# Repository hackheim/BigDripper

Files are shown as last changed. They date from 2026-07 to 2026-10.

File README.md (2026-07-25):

# Big Dripper 

### BigDripper – Controller Board and Operating Principle

BigDripper is Hackheim’s version of the classic bicycle-mounted water printer (see links below). The printer is being developed as a community project, with the goal of having it completed by the end of September 2026.

The printer consists of 16 solenoid valves mounted in a row across the bicycle trailer. The valves are supplied with water from a tank and pump. When a valve is opened briefly, it releases a small amount of water onto the ground, forming a single pixel. Together, the 16 valves produce one vertical column of 16 pixels. As the bicycle moves forward and new columns are printed in sequence, the trailer effectively operates as a large-scale dot-matrix printer.

An encoder measures the distance travelled by the bicycle. Rather than advancing through the image at fixed time intervals, the controller selects the next column after the bicycle has travelled a predefined distance. This helps maintain the proportions of the printed text or graphics even when the cycling speed varies.

### Controller board

The controller is based on an ESP32-S3 DevKitC-1, which plugs into a custom-designed carrier board. To make the board easy to maintain and repair—and also suitable for educational use and soldering workshops—we have chosen to use through-hole components throughout the carrier board.

The board has a nominal input voltage of 12 V, which is also the operating voltage of the solenoid valves. A TL2575-based switching regulator generates 5 V for the ESP32 development board and the other logic circuitry.

The regulator itself supports an input voltage of up to 40 V. However, the input voltage is also supplied directly to the solenoid valves. When using a voltage higher than 12 V, both the valves and all other components connected to the input-voltage rail must therefore be rated for the selected voltage.

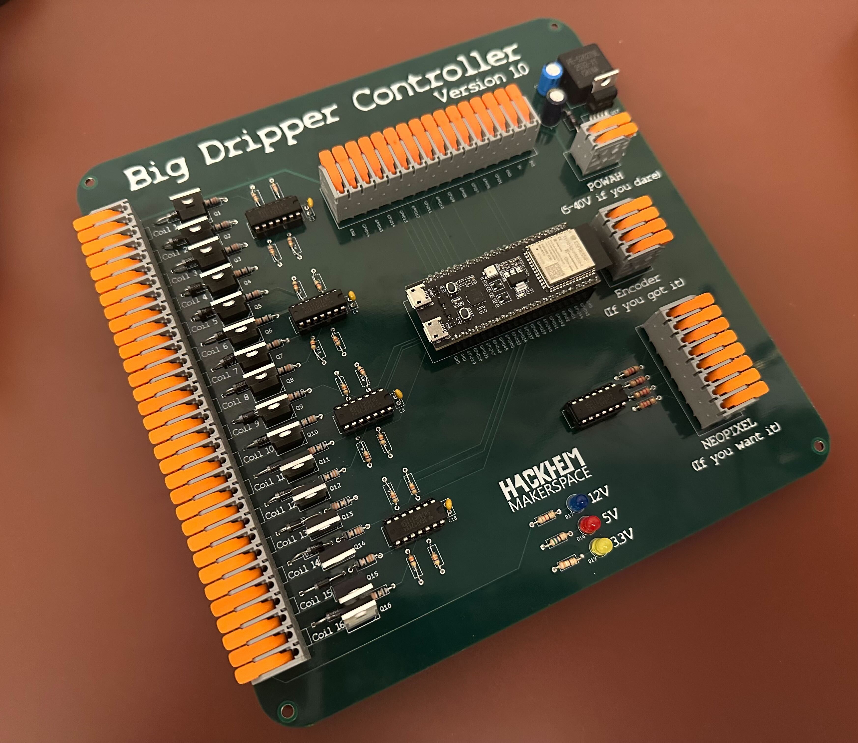
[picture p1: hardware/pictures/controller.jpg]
controller


### Solenoid valve control

The 16 valve outputs are controlled by IRL540N MOSFETs in a low-side switching configuration. The control signals from the ESP32 use 3.3 V logic and are therefore routed through SN74HCT125NE4 buffers powered from 5 V. These buffers provide logic-level translation and drive the MOSFET gates at a higher and more suitable voltage.

Each MOSFET gate is connected to its buffer output through a 33-ohm series resistor. The control signals also have 47-kilohm pull-down resistors, ensuring that the valves remain switched off while the ESP32 is starting, being reset, or not actively driving the outputs.

Each valve output is protected by a dedicated 1N4007 flyback diode. The diode suppresses the inductive voltage spike generated when the current through the solenoid coil is interrupted, protecting the MOSFET from excessive drain voltage.

### Connections and expansion options

The board has a dedicated input for an encoder with transistor outputs and A/B signals. An additional header provides access to 12 spare GPIO signals, together with 3.3 V, 5 V, and ground connections.

Four separate outputs are available for NeoPixel LEDs. These signals are also level-shifted from 3.3 V to 5 V using an SN74HCT125 buffer, and each data output includes a 330-ohm series resistor.

The board also includes indicator LEDs for the 12 V, 5 V, and 3.3 V supply rails, making it easy to verify that the different supply voltages are present.

All external inputs and outputs use WAGO board-to-wire lever connectors, allowing wires to be connected and removed easily without tools.

### Schematic

[schematic](./hardware/pdf/schematic.pdf)

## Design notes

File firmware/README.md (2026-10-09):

# Firmware demo

This code contains logic for controlling 16 valves and also reading input from a quadrature encoder. Valve control and quadrature logic is running on separate cores

## Building and flashing

1. Disconnect USB port
1. Press BOOT button
1. Reconnect USB port
1. pio run -t upload -t monitor
1. Press "Reset" on the ESP32

## Text input

1. Connect to the BigDripper SSID and enter the password "dripdrip1"
1. Go to http://bigdripper.local (fallback http://192.168.4.1) to queue text to print
1. Go to http://bigdripper.local/params for scaling/length/pause settings (user "admin", password "letmeprint9")
1. Each message prints in the font picked above the text box: Spleen (the original Spleen 8x16 font), Drip or Drip bold. Drip and Drip bold have A-Z, ÆØÅ, 0-9 and `. , ! ? - : '`; Spleen only has A-Z, 0-9 and space. Anything a font doesn't have prints as a space. The Invert button next to the fonts prints the message inverted: dry letters in a sprayed band, with 2 solid columns on each side. This uses a lot more water than normal text. Emoji are written as shortcodes (the web page has a button for each): `:smile:` `:sad:` `:big_smile:` `:neutral:` `:confused:` `:wink:` `:surprised:` `:tongue:` `:heart:` `:drop:` `:star:`. The length limit counts printed characters, so an emoji counts as one.

## Font

The Drip glyphs are defined in `font_design/gen_font.py`, and the Spleen font's bitmaps in `font_design/spleen_8x16.py`. After changing it, regenerate the preview and the firmware tables from this directory:

    python3 font_design/gen_font.py font_design/font_preview.txt
    python3 font_design/gen_font.py --c src/font_data.cpp

`font_design/host_test/` builds `font.cpp` on the host (needs `g++`) and checks the fonts, the emoji shortcodes and the length counting:

    sh font_design/host_test/run.sh

## Console preview

Check what the head prints at the bench, without water. Two extra build environments draw every column that fires on the serial console as one line of text; turn the wheel and the message scrolls by column by column.

    pio run -e preview -t upload -t monitor        # preview, valves fire as normal
    pio run -e preview-dry -t upload -t monitor    # preview, valves never open (dry run)

Add `--upload-port` / `--monitor-port` if the CP2102 isn't at the port in `platformio.ini`. On Linux it's usually `/dev/ttyUSB*` (e.g. `--upload-port /dev/ttyUSB1`), or watch it with `pio device monitor -p /dev/ttyUSB1 -b 115200`. If `pio` isn't on your PATH, it's `~/.platformio/penv/bin/pio`. A plain `pio run` still builds only the normal firmware. **Flash the normal firmware (`pio run -t upload`) again before riding**: a dry-run board prints `*** DRY RUN: valves disabled ***` at boot and its web page shows a red "DRY RUN — valves disabled" line.

The preview is on the CP2102 port ("UART", the one used for flashing; `Serial0` in the code), not the native USB port. If nothing shows up, check which port you're watching first.

How to read it: each line is one column, 16 characters, `#` = valve open, `.` = closed, COIL1 on the left. Columns appear top to bottom in the order they fire. **Rotate the screen 90° anticlockwise** (left edge down) and the text reads the right way up, first column on the left. It shows the coil bits actually written, so if the preview reads mirrored, the ground print is mirrored too. `HI` in Drip looks like this:

    -- HI [Drip] --
    ################
    .......##.......
    .......##.......
    .......##.......
    .......##.......
    .......##.......
    .......##.......
    .......##.......
    ################
    ................
    ................
    ................
    ##............##
    ##............##
    ################
    ##............##
    ##............##

Other lines: `-- mode: lines --` when the mode changes (Prime and Trace draw nothing, Lines draws its columns), `~~ skipped 3 ~~` when the wheel jumped past columns between two scans (those never fire on the ground either), and `!! dropped 12 lines` if the console fell behind a fast spin. Dropped lines only affect the preview, never the valves.

Under the hood these are the build flags `-D CONSOLE_PREVIEW=1` and `-D CONSOLE_PREVIEW_DRY_RUN=1`, which also work on their own.

## Debugging

1. Make sure that the CP210x driver is installed oin the machine you are debugging on. If not, the UART port will not enumerate

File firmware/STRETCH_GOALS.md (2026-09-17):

# Stretch goal

* Use for extra switches on control panel ?
    * Font change ?
    * Bold / Italics ?

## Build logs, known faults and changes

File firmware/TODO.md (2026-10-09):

# TODO

[x] The column should not be on until the next column, but it should "blink" so that we print a column as a burst. How long  this burst is should be specified as a new parameter in the parameter page.
[x] Can we force the web page to refresh, so that a user doesn't get confused by a cached page after a reboot ?

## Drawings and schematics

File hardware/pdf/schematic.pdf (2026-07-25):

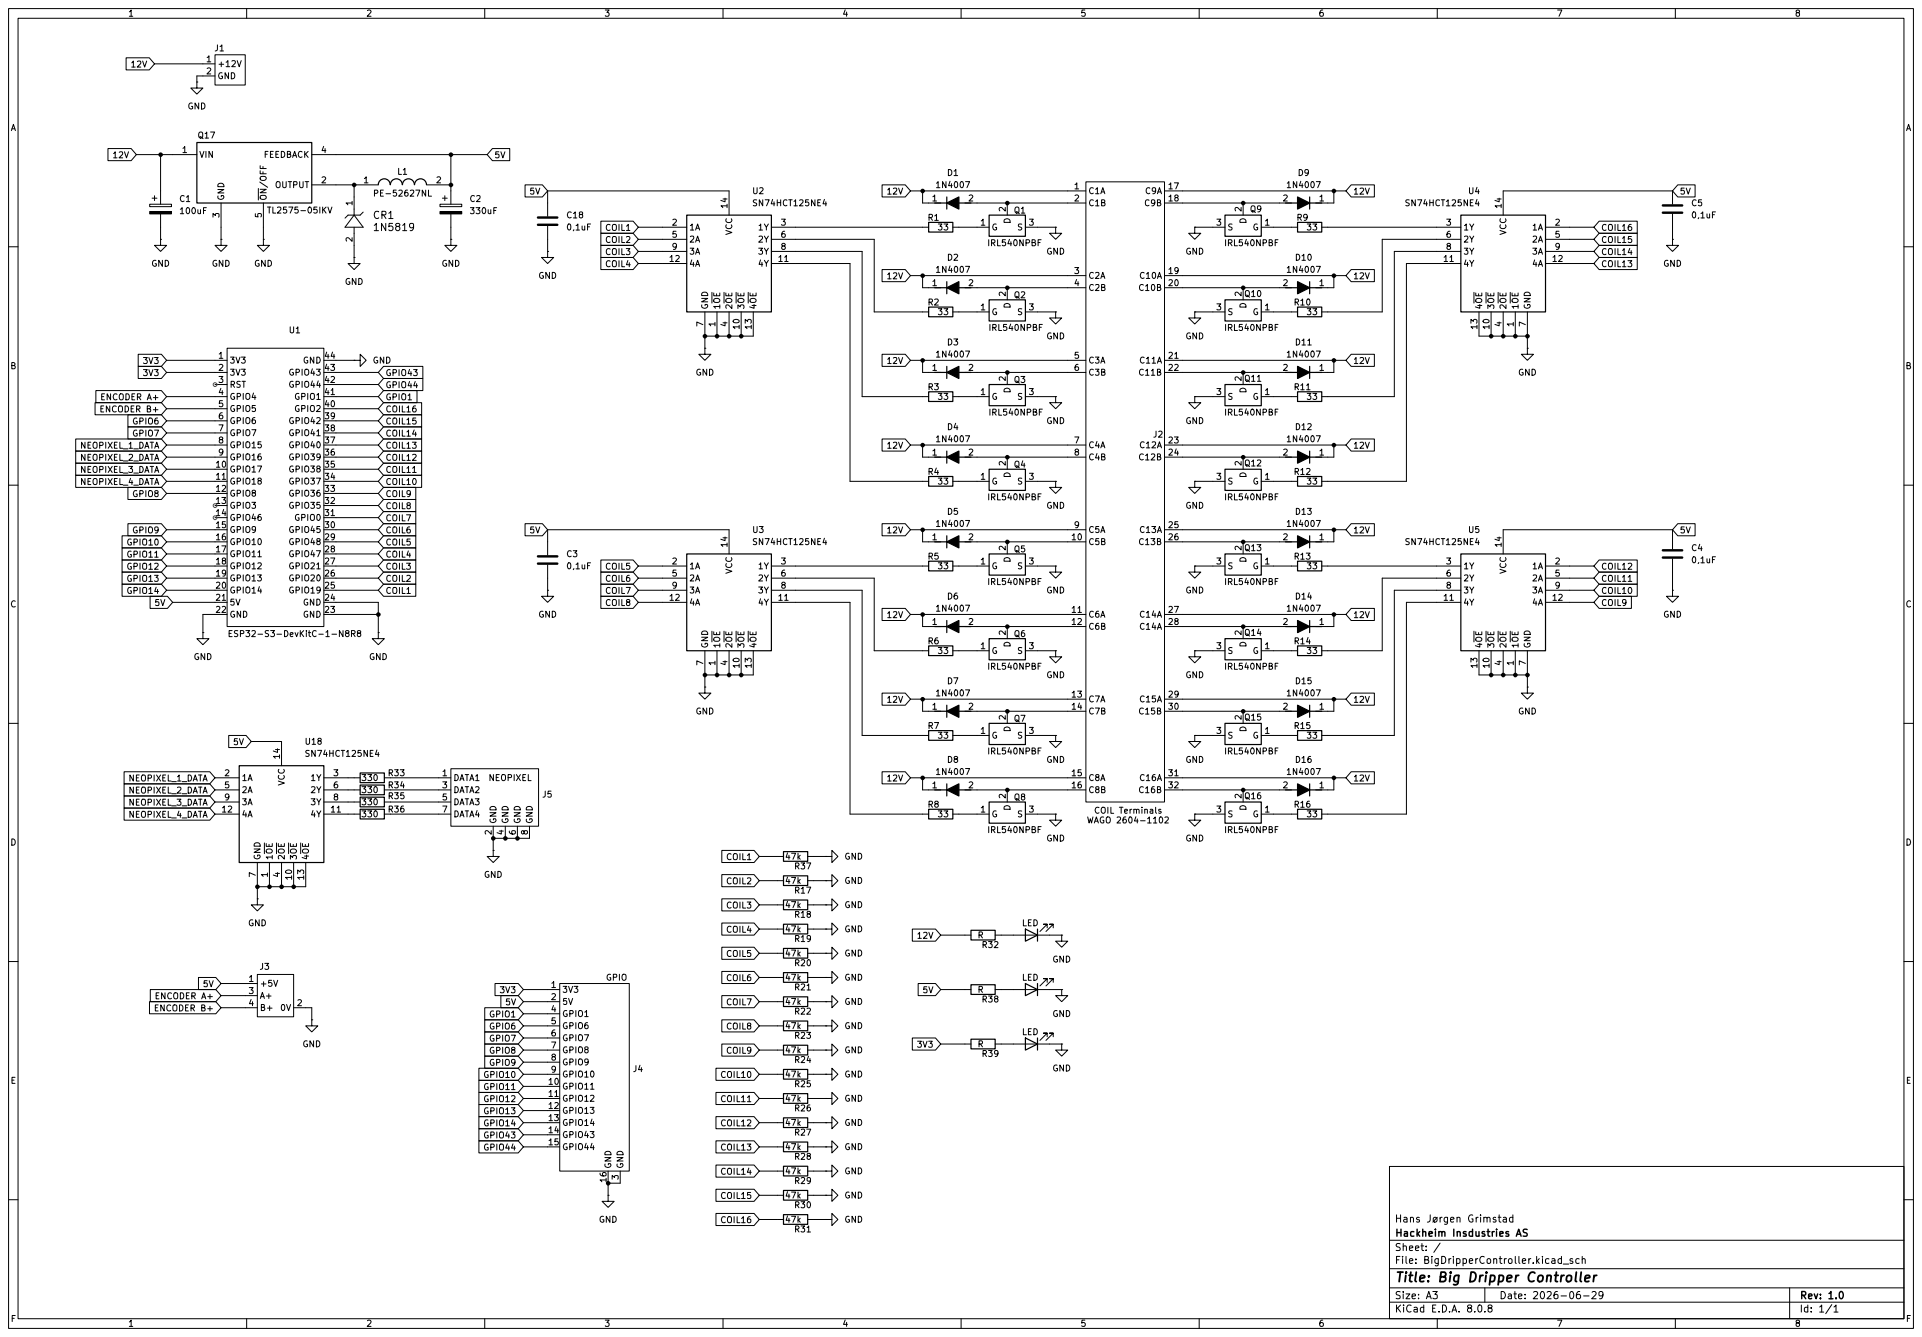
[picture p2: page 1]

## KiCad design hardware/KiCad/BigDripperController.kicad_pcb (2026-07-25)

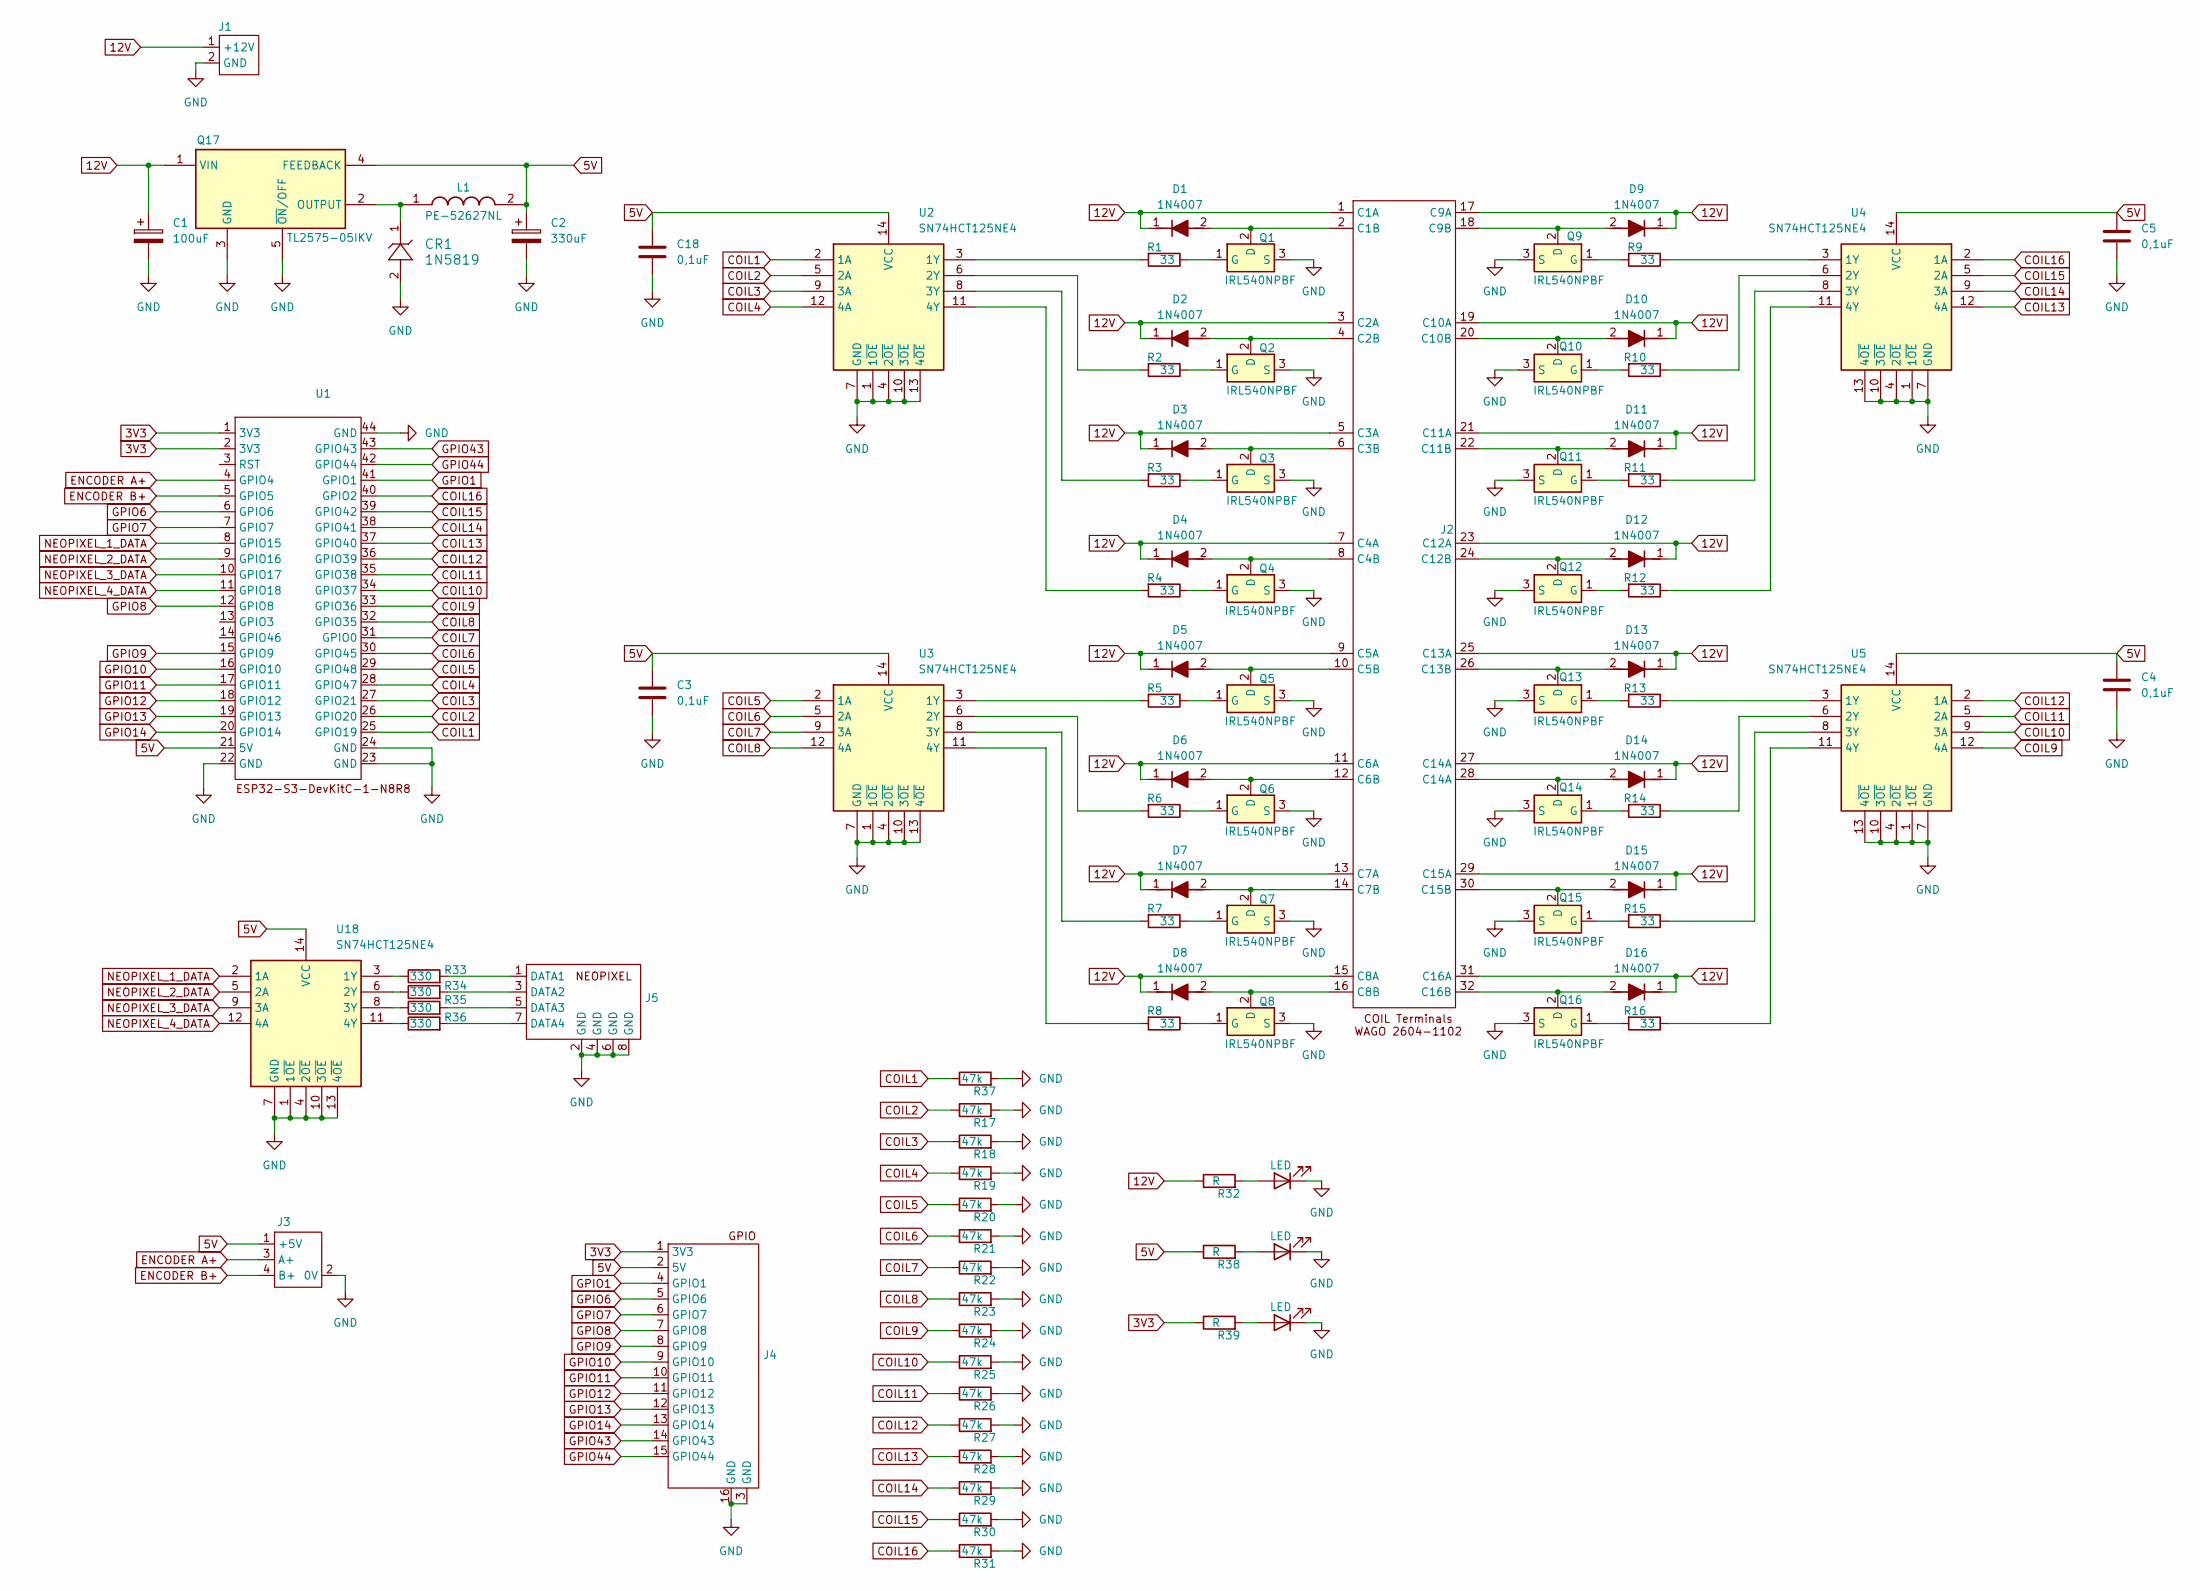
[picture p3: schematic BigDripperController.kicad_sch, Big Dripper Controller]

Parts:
C1: 100uF; CAP ALUM 10UF 20% 25V RADIAL TH - WÜRTH - 860020472003
C2: 330uF; CAP ALUM 10UF 20% 25V RADIAL TH - WÜRTH - 860020472003
C3, C4, C5, C18: 0,1uF; CAP0,1uF_K104K15X7RF5TH5V
CR1: 1N5819
D1, D2, D3, D4, D5, D6, D7, D8, D9, D10, D11, D12, D13, D14, D15, D16: 1N4007; Mouser Part Number 637-1N4007
D17, D18, D19: LED; LED_D5.0mm
J1: BigDripperPowerConnector-WAGO2604-1102
J2: BigDripperCoilConnector-WAGO2604-1102
J3: BigDripperEncoderConnector-WAGO2604-1102
J4: BigDripperGPIOConnector-WAGO2604-1102
J5: BigDripperNeopixelConnector-WAGO2604-1102
L1: PE-52627NL; PE52627NL; Mouser Part Number 673-PE-52627NL
Q1, Q2, Q3, Q4, Q5, Q6, Q7, Q8, Q9, Q10, Q11, Q12, Q13, Q14, Q15, Q16: IRL540NPBF; Mouser Part Number 942-IRL540NPBF
Q17: TL2575-05IKV; Mouser Part Number 595-TL2575-05IKV
R1, R2, R3, R4, R5, R6, R7, R8, R9, R10, R11, R12, R13, R14, R15, R16: 33; R_Axial_DIN0207_L6.3mm_D2.5mm_P10.16mm_Horizontal
R17, R18, R19, R20, R21, R22, R23, R24, R25, R26, R27, R28, R29, R30, R31, R37: 47k; R_Axial_DIN0207_L6.3mm_D2.5mm_P10.16mm_Horizontal
R32, R38, R39: R; R_Axial_DIN0207_L6.3mm_D2.5mm_P10.16mm_Horizontal
R33, R34, R35, R36: 330; R_Axial_DIN0207_L6.3mm_D2.5mm_P10.16mm_Horizontal
U1: ESP32-S3-DevKitC-1-N8R8
U2, U3, U4, U5, U18: SN74HCT125NE4; DIP14; Mouser Part Number 595-SN74HCT125NE4

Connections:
3V3: J4.1 (3V3), R39.1, U1.1 (3V3), U1.2 (3V3)
5V: C2.1, C3.1, C4.1, C5.1, C18.1, J3.1 (+5V), J4.2 (5V), L1.2 (1-), Q17.4 (FEEDBACK), R38.1, U1.21 (5V), U2.14 (VCC), U3.14 (VCC), U4.14 (VCC), U5.14 (VCC), U18.14 (VCC)
12V: C1.1, D1.1 (K), D2.1 (K), D3.1 (K), D4.1 (K), D5.1 (K), D6.1 (K), D7.1 (K), D8.1 (K), D9.1 (K), D10.1 (K), D11.1 (K), D12.1 (K), D13.1 (K), D14.1 (K), D15.1 (K), D16.1 (K), J1.1 (+12V), J2.1 (C1A), J2.3 (C2A), J2.5 (C3A), J2.7 (C4A), J2.9 (C5A), J2.11 (C6A), J2.13 (C7A), J2.15 (C8A), J2.17 (C9A), J2.19 (C10A), J2.21 (C11A), J2.23 (C12A), J2.25 (C13A), J2.27 (C14A), J2.29 (C15A), J2.31 (C16A), Q17.1 (VIN), R32.1
COIL1: R37.1, U1.25 (GPIO19), U2.2 (1A)
COIL2: R17.1, U1.26 (GPIO20), U2.5 (2A)
COIL3: R18.1, U1.27 (GPIO21), U2.9 (3A)
COIL4: R19.1, U1.28 (GPIO47), U2.12 (4A)
COIL5: R20.1, U1.29 (GPIO48), U3.2 (1A)
COIL6: R21.1, U1.30 (GPIO45), U3.5 (2A)
COIL7: R22.1, U1.31 (GPIO0), U3.9 (3A)
COIL8: R23.1, U1.32 (GPIO35), U3.12 (4A)
COIL9: R24.1, U1.33 (GPIO36), U5.12 (4A)
COIL10: R25.1, U1.34 (GPIO37), U5.9 (3A)
COIL11: R26.1, U1.35 (GPIO38), U5.5 (2A)
COIL12: R27.1, U1.36 (GPIO39), U5.2 (1A)
COIL13: R28.1, U1.37 (GPIO40), U4.12 (4A)
COIL14: R29.1, U1.38 (GPIO41), U4.9 (3A)
COIL15: R30.1, U1.39 (GPIO42), U4.5 (2A)
COIL16: R31.1, U1.40 (GPIO2), U4.2 (1A)
ENCODER A+: J3.3 (A+), U1.4 (GPIO4)
ENCODER B+: J3.4 (B+), U1.5 (GPIO5)
GND: C1.2, C2.2, C3.2, C4.2, C5.2, C18.2, CR1.2, D17.1 (K), D18.1 (K), D19.1 (K), J1.2 (GND), J3.2 (0V), J4.3 (GND), J4.16 (GND), J5.2 (GND), J5.4 (GND), J5.6 (GND), J5.8 (GND), Q1.3 (S), Q2.3 (S), Q3.3 (S), Q4.3 (S), Q5.3 (S), Q6.3 (S), Q7.3 (S), Q8.3 (S), Q9.3 (S), Q10.3 (S), Q11.3 (S), Q12.3 (S), Q13.3 (S), Q14.3 (S), Q15.3 (S), Q16.3 (S), Q17.3 (GND), Q17.5 (~ON/OFF), R17.2, R18.2, R19.2, R20.2, R21.2, R22.2, R23.2, R24.2, R25.2, R26.2, R27.2, R28.2, R29.2, R30.2, R31.2, R37.2, U1.22 (GND), U1.23 (GND), U1.24 (GND), U1.44 (GND), U2.1 (1~OE), U2.4 (2~OE), U2.7 (GND), U2.10 (3~OE), U2.13 (4~OE), U3.1 (1~OE), U3.4 (2~OE), U3.7 (GND), U3.10 (3~OE), U3.13 (4~OE), U4.1 (1~OE), U4.4 (2~OE), U4.7 (GND), U4.10 (3~OE), U4.13 (4~OE), U5.1 (1~OE), U5.4 (2~OE), U5.7 (GND), U5.10 (3~OE), U5.13 (4~OE), U18.1 (1~OE), U18.4 (2~OE), U18.7 (GND), U18.10 (3~OE), U18.13 (4~OE)
GPIO1: J4.4 (GPIO1), U1.41 (GPIO1)
GPIO6: J4.5 (GPIO6), U1.6 (GPIO6)
GPIO7: J4.6 (GPIO7), U1.7 (GPIO7)
GPIO8: J4.7 (GPIO8), U1.12 (GPIO8)
GPIO9: J4.8 (GPIO9), U1.15 (GPIO9)
GPIO10: J4.9 (GPIO10), U1.16 (GPIO10)
GPIO11: J4.10 (GPIO11), U1.17 (GPIO11)
GPIO12: J4.11 (GPIO12), U1.18 (GPIO12)
GPIO13: J4.12 (GPIO13), U1.19 (GPIO13)
GPIO14: J4.13 (GPIO14), U1.20 (GPIO14)
GPIO43: J4.14 (GPIO43), U1.43 (GPIO43)
GPIO44: J4.15 (GPIO44), U1.42 (GPIO44)
NEOPIXEL_1_DATA: U1.8 (GPIO15), U18.2 (1A)
NEOPIXEL_2_DATA: U1.9 (GPIO16), U18.5 (2A)
NEOPIXEL_3_DATA: U1.10 (GPIO17), U18.9 (3A)
NEOPIXEL_4_DATA: U1.11 (GPIO18), U18.12 (4A)
unnamed: D1.2 (A), J2.2 (C1B), Q1.2 (D)
unnamed: D2.2 (A), J2.4 (C2B), Q2.2 (D)
unnamed: D3.2 (A), J2.6 (C3B), Q3.2 (D)
unnamed: D4.2 (A), J2.8 (C4B), Q4.2 (D)
unnamed: D5.2 (A), J2.10 (C5B), Q5.2 (D)
unnamed: D6.2 (A), J2.12 (C6B), Q6.2 (D)
unnamed: D7.2 (A), J2.14 (C7B), Q7.2 (D)
unnamed: D8.2 (A), J2.16 (C8B), Q8.2 (D)
unnamed: D9.2 (A), J2.18 (C9B), Q9.2 (D)
unnamed: D10.2 (A), J2.20 (C10B), Q10.2 (D)
unnamed: D11.2 (A), J2.22 (C11B), Q11.2 (D)
unnamed: D12.2 (A), J2.24 (C12B), Q12.2 (D)
unnamed: D13.2 (A), J2.26 (C13B), Q13.2 (D)
unnamed: D14.2 (A), J2.28 (C14A), Q14.2 (D)
unnamed: D15.2 (A), J2.30 (C15B), Q15.2 (D)
unnamed: D16.2 (A), J2.32 (C16B), Q16.2 (D)
unnamed: D17.2 (A), R32.2
unnamed: D18.2 (A), R38.2
unnamed: D19.2 (A), R39.2
unnamed: J5.1 (DATA1), R33.2
unnamed: J5.3 (DATA2), R34.2
unnamed: J5.5 (DATA3), R35.2
unnamed: J5.7 (DATA4), R36.2
unnamed: CR1.1, L1.1 (1+), Q17.2 (OUTPUT)
unnamed: Q1.1 (G), R1.1
unnamed: Q2.1 (G), R2.1
unnamed: Q3.1 (G), R3.1
unnamed: Q4.1 (G), R4.1
unnamed: Q5.1 (G), R5.1
unnamed: Q6.1 (G), R6.1
unnamed: Q7.1 (G), R7.1
unnamed: Q8.1 (G), R8.1
unnamed: Q9.1 (G), R9.2
unnamed: Q10.1 (G), R10.2
unnamed: Q11.1 (G), R11.2
unnamed: Q12.1 (G), R12.2
unnamed: Q13.1 (G), R13.2
unnamed: Q14.1 (G), R14.2
unnamed: Q15.1 (G), R15.2
unnamed: Q16.1 (G), R16.2
unnamed: R1.2, U2.3 (1Y)
unnamed: R2.2, U2.6 (2Y)
unnamed: R3.2, U2.8 (3Y)
unnamed: R4.2, U2.11 (4Y)
unnamed: R5.2, U3.3 (1Y)
unnamed: R6.2, U3.6 (2Y)
unnamed: R7.2, U3.8 (3Y)
unnamed: R8.2, U3.11 (4Y)
unnamed: R9.1, U4.3 (1Y)
unnamed: R10.1, U4.6 (2Y)
unnamed: R11.1, U4.8 (3Y)
unnamed: R12.1, U4.11 (4Y)
unnamed: R13.1, U5.3 (1Y)
unnamed: R14.1, U5.6 (2Y)
unnamed: R15.1, U5.8 (3Y)
unnamed: R16.1, U5.11 (4Y)
unnamed: R33.1, U18.3 (1Y)
unnamed: R34.1, U18.6 (2Y)
unnamed: R35.1, U18.8 (3Y)
unnamed: R36.1, U18.11 (4Y)

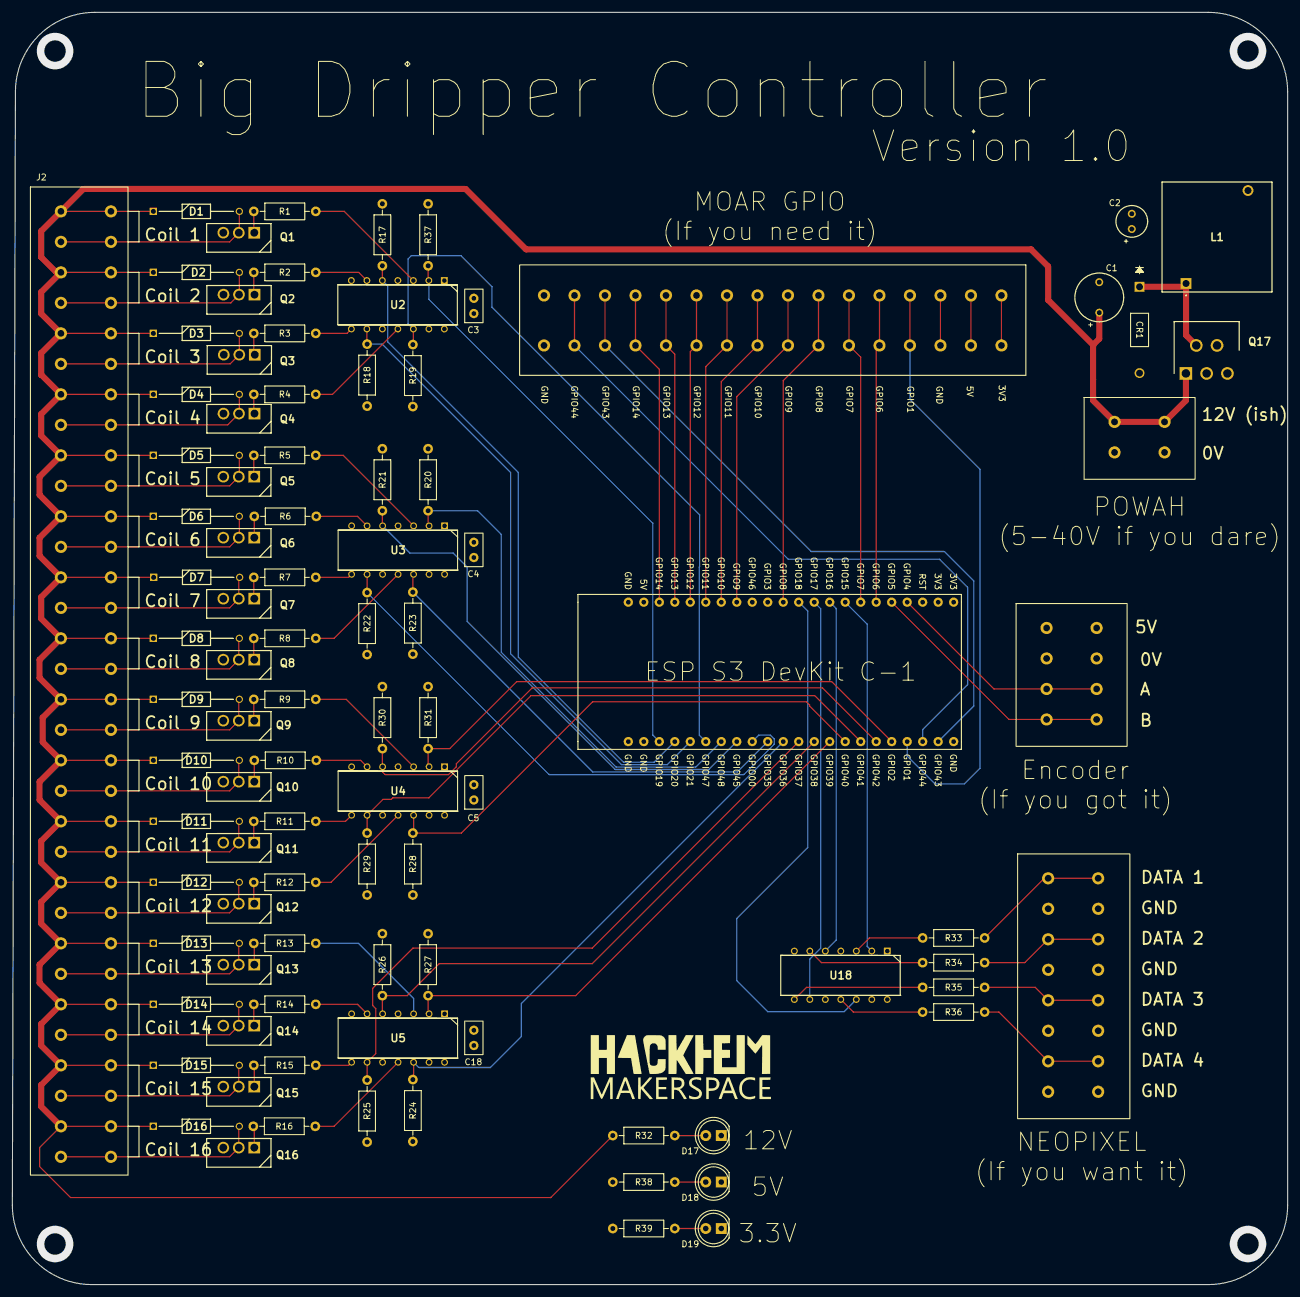
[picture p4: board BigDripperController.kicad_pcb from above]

Board: 4 copper layers, 209.1 x 208.6 mm, 94 parts (0 on the bottom side), 98 nets.

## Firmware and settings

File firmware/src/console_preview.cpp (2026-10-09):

#include "console_preview.h"

#if defined(CONSOLE_PREVIEW) || defined(CONSOLE_PREVIEW_DRY_RUN)

// Serial0 is UART0 (GPIO43/44), which is what the CP2102 bridge carries: the
// same cable and port used for flashing. Plain `Serial` is native USB here
// (ARDUINO_USB_CDC_ON_BOOT=1).
static const uint32_t PREVIEW_BAUD = 115200;

// Smooths bursts: a 16-char line + CRLF is 18 bytes, so this holds ~220
// lines on top of the queue below.
static const size_t PREVIEW_TX_BUFFER = 4096;

#ifdef CONSOLE_PREVIEW

#define PREVIEW_CORE 0
static const UBaseType_t PREVIEW_QUEUE_DEPTH = 256;

enum class ItemKind : uint8_t { Column, Message, Mode, Skipped };

struct Item {
  ItemKind kind;
  uint16_t bits;      // Column
  int32_t n;          // Skipped: column count. Mode: PrintMode.
  uint32_t dropped;   // lines dropped just before this one
  char text[48];      // Message, truncated
};

static QueueHandle_t preview_queue = NULL;

// Only the print engine (valve task) pushes, so this needs no lock. It's
// carried by the next item that does fit, so the drop note lands exactly
// where the gap in the picture is.
static uint32_t pending_drops = 0;

static void push(Item &item) {
  if (preview_queue == NULL) return;
  item.dropped = pending_drops;
  if (xQueueSend(preview_queue, &item, 0) == pdTRUE) {
    pending_drops = 0;
  } else {
    pending_drops++;
  }
}

void console_preview_column(uint16_t bits) {
  Item item;
  item.kind = ItemKind::Column;
  item.bits = bits;
  push(item);
}

void console_preview_message(const QueuedText &m, bool is_default) {
  Item item;
  item.kind = ItemKind::Message;
  // Cap the text so the font and flags always fit, backing off so a UTF-8
  // character (ÆØÅ) isn't cut in half.
  int len = m.text.length();
  if (len > 20) {
    len = 20;
    while (len > 0 && (m.text[len] & 0xC0) == 0x80) len--;
  }
  snprintf(item.text, sizeof(item.text), "%.*s [%s%s]%s", len, m.text.c_str(),
           font_label(m.font), m.invert ? ", inverted" : "",
           is_default ? " (default)" : "");
  push(item);
}

void console_preview_mode(PrintMode mode) {
  Item item;
  item.kind = ItemKind::Mode;
  item.n = (int32_t)mode;
  push(item);
}

void console_preview_skipped(int32_t n) {
  Item item;
  item.kind = ItemKind::Skipped;
  item.n = n;
  push(item);
}

static void preview_task(void *arg) {
  Item item;
  char line[80];
  for (;;) {
    xQueueReceive(preview_queue, &item, portMAX_DELAY);

    if (item.dropped) {
      Serial0.printf("!! dropped %lu lines\r\n", (unsigned long)item.dropped);
    }

    switch (item.kind) {
      case ItemKind::Column: {
        uint16_t bit = 0x8000;  // COIL1 first, like set_coil_state()
        for (int i = 0; i < 16; i++) {
          line[i] = (item.bits & bit) ? '#' : '.';
          bit >>= 1;
        }
        line[16] = '\r';
        line[17] = '\n';
        // Blocks once the TX buffer is full, which is fine here: it only
        // backs up this queue, never the valve task.
        Serial0.write((const uint8_t *)line, 18);
        break;
      }
      case ItemKind::Message:
        Serial0.printf("-- %s --\r\n", item.text);
        break;
      case ItemKind::Mode:
        Serial0.printf("-- mode: %s --\r\n", mode_name((PrintMode)item.n));
        break;
      case ItemKind::Skipped:
        Serial0.printf("~~ skipped %ld ~~\r\n", (long)item.n);
        break;
    }
  }
}

#endif  // CONSOLE_PREVIEW

void console_preview_begin() {
  Serial0.setTxBufferSize(PREVIEW_TX_BUFFER);  // must come before begin()
  Serial0.begin(PREVIEW_BAUD);
  Serial0.println();

#ifdef CONSOLE_PREVIEW_DRY_RUN
  // So a dry-run board on the bike isn't mistaken for a broken one. Also on
  // native USB, in case that's the port someone plugs into.
  static const char BANNER[] = "*** DRY RUN: valves disabled (CONSOLE_PREVIEW_DRY_RUN) ***";
  Serial0.println(BANNER);
  Serial.println(BANNER);
#endif

#ifdef CONSOLE_PREVIEW
  Serial0.println("-- console preview: one line per column, COIL1 on the left --");
  Serial0.println("-- rotate 90 degrees anticlockwise to read --");
  preview_queue = xQueueCreate(PREVIEW_QUEUE_DEPTH, sizeof(Item));
  // Priority 1, below the encoder task: it only ever waits on the queue or
  // the UART, so IDLE0 keeps running and the watchdog stays fed.
  xTaskCreatePinnedToCore(preview_task, "preview", 3072, NULL, 1, NULL, PREVIEW_CORE);
#endif
}

#endif  // CONSOLE_PREVIEW || CONSOLE_PREVIEW_DRY_RUN

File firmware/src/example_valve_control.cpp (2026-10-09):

#include <Arduino.h>
#include <Adafruit_NeoPixel.h>
#include "esp_timer.h"
#include "soc/gpio_struct.h"
#include "wifi_text_input.h"
#include "params.h"
#include "font.h"
#include "text_queue.h"
#include "mode.h"
#include "test_pattern.h"
#include "console_preview.h"

// COIL1..COIL16 -> ESP32-S3 GPIO, in order. The state vector is MSB-first:
// bit 15 = COIL1 (coils[0]) ... bit 0 = COIL16 (coils[15]).
const int NUM_COILS = 16;
const int NUM_NEOPIXEL_STRIPS = 4;
const uint8_t coils[NUM_COILS] = {9, 11, 10, 12, 14, 13, 1, 6, 7, 8, 38, 39, 40, 41, 42, 2};
const uint8_t neopixels[NUM_NEOPIXEL_STRIPS] = {15, 16, 17, 18};

// Per-coil register info for set_coil_state(), filled in by coils_begin().
// GPIO 0-31 live in bank 0 (GPIO.out_w1ts/out_w1tc); GPIO 32+ live in bank 1
// (GPIO.out1_w1ts.val/out1_w1tc.val). Precomputing which bank each coil's pin
// falls in, and its bit mask within that bank, means set_coil_state() can
// turn a 16-bit pattern into 4 register writes instead of 16 digitalWrite()
// calls, so every coil switches in the same instant rather than one at a time.
static uint32_t coil_mask[NUM_COILS];
static bool coil_is_bank1[NUM_COILS];

void coils_begin() {
  for (int i = 0; i < NUM_COILS; i++) {
    uint8_t pin = coils[i];
    if (pin < 32) {
      coil_is_bank1[i] = false;
      coil_mask[i] = 1UL << pin;
    } else {
      coil_is_bank1[i] = true;
      coil_mask[i] = 1UL << (pin - 32);
    }
  }
}

// Strip 1 (first neopixel GPIO) pulses red; strip 2 (second GPIO) runs a
// yellow Cylon eye. The other two pins are reserved and aren't driven yet.
const int GLOW_STRIP_PIXELS = 48;
const int CYLON_STRIP_PIXELS = 28;
Adafruit_NeoPixel glow_strip(GLOW_STRIP_PIXELS, neopixels[0], NEO_GRB + NEO_KHZ800);
Adafruit_NeoPixel cylon_strip(CYLON_STRIP_PIXELS, neopixels[1], NEO_GRB + NEO_KHZ800);

// Encoder
const int NUM_ENCODER_CHANNELS = 2;
const uint8_t encoder[NUM_ENCODER_CHANNELS] = {4,5};

// --- Interrupt-driven quadrature decoder -----------------------------------
//
// State is (A << 1) | B. Indexing this table with (previous << 2) | current
// gives the step: +1 clockwise, -1 counter-clockwise, and 0 for the six
// impossible transitions (both channels changing at once), which is what
// contact bounce and missed steps look like. Rejecting those instead of
// guessing is what keeps the count from drifting on a cheap encoder.
//
// DRAM_ATTR keeps the table out of flash. An IRAM ISR must not touch flash,
// because the cache is disabled during flash writes and the fetch would fault.
static const DRAM_ATTR int8_t QUAD_TABLE[16] = {
   0, -1, +1,  0,
  +1,  0,  0, -1,
  -1,  0,  0, +1,
   0, +1, -1,  0
};

// Same reason: plain globals live in DRAM, so cache the pins here rather than
// reading the const encoder[] array (.rodata, i.e. flash) from the ISR.
static uint8_t enc_pin_a = 0;
static uint8_t enc_pin_b = 0;

static volatile int32_t encoder_raw = 0;   // quarter-steps, not detents
static volatile uint8_t encoder_prev = 0;
static portMUX_TYPE encoder_mux = portMUX_INITIALIZER_UNLOCKED;

// Set by the encoder task before it attaches the interrupt, so the ISR can wake
// it. A plain global lives in .bss (DRAM), which an IRAM ISR may read.
static volatile TaskHandle_t encoder_task_handle = NULL;

// Set by valve_task (via print_engine_run()) so the same ISR can also wake the
// print engine immediately on encoder movement, instead of it polling on a
// fixed tick. Independent of encoder_task_handle's publish order — the ISR
// null-checks each handle on its own.
static volatile TaskHandle_t valve_task_handle = NULL;

// Most detented encoders run through a full 4-state cycle per click, so shift
// by 2 to report detents. Set to 0 to count every edge instead.
static const int ENCODER_DETENT_SHIFT = 2;

static void ARDUINO_ISR_ATTR encoder_isr() {
  uint8_t state = (digitalRead(enc_pin_a) << 1) | digitalRead(enc_pin_b);

  portENTER_CRITICAL_ISR(&encoder_mux);
  encoder_raw += QUAD_TABLE[(encoder_prev << 2) | state];
  encoder_prev = state;
  portEXIT_CRITICAL_ISR(&encoder_mux);

  // Wake the encoder task and the valve task instead of having them poll. The
  // ISR stays short: it only counts, the tasks do anything expensive.
  BaseType_t higher_woken = pdFALSE;
  if (encoder_task_handle != NULL) {
    BaseType_t woken = pdFALSE;
    vTaskNotifyGiveFromISR(encoder_task_handle, &woken);
    higher_woken |= woken;
  }
  if (valve_task_handle != NULL) {
    BaseType_t woken = pdFALSE;
    vTaskNotifyGiveFromISR(valve_task_handle, &woken);
    higher_woken |= woken;
  }
  portYIELD_FROM_ISR(higher_woken);
}

// Safe to call from loop(): int32_t is not atomic against a concurrent ISR on
// the other core, so take the same lock the ISR uses.
int32_t encoder_position() {
  portENTER_CRITICAL(&encoder_mux);
  int32_t raw = encoder_raw;
  portEXIT_CRITICAL(&encoder_mux);

  // Arithmetic shift floors toward negative infinity. Dividing by 4 would
  // truncate toward zero and make the detent straddling zero twice as wide.
  return raw >> ENCODER_DETENT_SHIFT;
}

void encoder_zero() {
  portENTER_CRITICAL(&encoder_mux);
  encoder_raw = 0;
  portEXIT_CRITICAL(&encoder_mux);
}

void encoder_begin() {
  enc_pin_a = encoder[0];
  enc_pin_b = encoder[1];

  // Seed the previous state, otherwise the first edge is decoded against a
  // state the encoder was never in and can produce one bogus step.
  encoder_prev = (digitalRead(enc_pin_a) << 1) | digitalRead(enc_pin_b);

  // Both channels, both edges — a quadrature cycle has four transitions and
  // dropping any of them halves the resolution and breaks the state table.
  attachInterrupt(digitalPinToInterrupt(enc_pin_a), encoder_isr, CHANGE);
  attachInterrupt(digitalPinToInterrupt(enc_pin_b), encoder_isr, CHANGE);
}
// ---------------------------------------------------------------------------


// --- Core assignment -------------------------------------------------------
//
// Arduino's loopTask is pinned to ARDUINO_RUNNING_CORE, which this board sets to
// 1 (see the board manifest's extra_flags). So core 1 is where setup()/loop()
// already run, and core 0 is otherwise idle in this sketch.
#define ENCODER_CORE 0
#define VALVE_CORE   1

// Defined below. This is a .cpp, so unlike an .ino there is no automatic
// prototype generation.
void test_GPIO_outputs();
void print_engine_run();
void coils_begin();

static void encoder_task(void *arg) {
  // Publish the handle before attaching, so the ISR never fires with it unset.
  encoder_task_handle = xTaskGetCurrentTaskHandle();

  // attachInterrupt MUST be called from this task, not from setup(). The first
  // attachInterrupt anywhere in the sketch calls gpio_install_isr_service(),
  // which allocates the shared GPIO interrupt on whatever core is executing at
  // that moment (see __attachInterruptFunctionalArg in esp32-hal-gpio.c).
  // Calling it from setup() would bind the ISR to core 1 no matter where this
  // task runs. Caveat: that service is shared, so every GPIO interrupt added
  // later also lands on this core.
  encoder_begin();

  log_i("encoder task + ISR on core %d", xPortGetCoreID());

  // Logging every single detent works fine for a slow test turn, but a fast
  // spin can notify this task faster than a UART write at 115200 baud can
  // drain (log_i's underlying uart_tx busy-waits for FIFO space), which was
  // starving IDLE0 on this core long enough to trip the task watchdog. Cap
  // how often we actually log; position tracking itself stays uncapped.
  const uint32_t LOG_INTERVAL_MS = 50;
  uint32_t last_log_ms = 0;

  int32_t last = encoder_position();
  for (;;) {
    // Block until the ISR reports an edge. No polling, so IDLE0 keeps running
    // and the task watchdog stays fed.
    ulTaskNotifyTake(pdTRUE, portMAX_DELAY);

    int32_t pos = encoder_position();
    if (pos != last) {
      uint32_t now = millis();
      if (now - last_log_ms >= LOG_INTERVAL_MS) {
        log_i("encoder %+ld (%s) [core %d]",
              (long)pos, pos > last ? "CW" : "CCW", xPortGetCoreID());
        last_log_ms = now;
      }
      last = pos;
    }
  }
}

static void valve_task(void *arg) {
  log_i("valve task on core %d", xPortGetCoreID());

  // Blocking sequencer; delay() inside a task is vTaskDelay, so it yields the
  // core rather than spinning.
  print_engine_run();  // never returns

  vTaskDelete(NULL);
}

// Slow red breathe: a sine wave keeps the fade smooth at both ends, unlike a
// linear ramp which looks like it "hangs" near full brightness/off.
// --- Neopixel power budget -------------------------------------------------
//
// All strips share a 1 A supply, so brightness is capped by design rather
// than measured at runtime. WS2812B figures, on the conservative side: ~20 mA
// per colour channel at full (255) and ~1 mA per pixel just for being
// powered, even when dark.
static constexpr float NEOPIXEL_BUDGET_MA = 1000.0f;
static constexpr float NEOPIXEL_MARGIN_MA = 100.0f;   // headroom for the estimate being off
static constexpr float MA_PER_CHANNEL_FULL = 20.0f;
static constexpr float MA_IDLE_PER_PIXEL = 1.0f;

static constexpr float NEOPIXEL_IDLE_MA =
    (GLOW_STRIP_PIXELS + CYLON_STRIP_PIXELS) * MA_IDLE_PER_PIXEL;

// Cylon eye colour: a warm yellow (pure 255,255,0 looks greenish on WS2812s).
static constexpr uint8_t CYLON_R = 255;
static constexpr uint8_t CYLON_G = 170;
static constexpr uint8_t CYLON_B = 0;

// The trail fades by CYLON_DECAY every frame and the head adds at most one
// full pixel's worth of light per frame, so the total lit amount is bounded
// by the geometric series 1 / (1 - CYLON_DECAY) pixels at full colour.
static constexpr float CYLON_DECAY = 0.8f;
static constexpr float CYLON_MAX_MA =
    (1.0f / (1.0f - CYLON_DECAY)) *
    ((CYLON_R + CYLON_G + CYLON_B) / 255.0f) * MA_PER_CHANNEL_FULL;

// Whatever is left goes to the red glow. All 48 pixels light up at once at
// the top of the pulse, so this is the strip that actually needs capping.
static constexpr float GLOW_AVAILABLE_MA =
    NEOPIXEL_BUDGET_MA - NEOPIXEL_MARGIN_MA - NEOPIXEL_IDLE_MA - CYLON_MAX_MA;
static constexpr float GLOW_RED_MAX_F =
    GLOW_AVAILABLE_MA / GLOW_STRIP_PIXELS / MA_PER_CHANNEL_FULL * 255.0f;
static constexpr uint8_t GLOW_RED_MAX = GLOW_RED_MAX_F > 255.0f ? 255 : (uint8_t)GLOW_RED_MAX_F;

static_assert(GLOW_AVAILABLE_MA > 0, "neopixel budget exhausted before the glow strip");
static_assert(NEOPIXEL_IDLE_MA + CYLON_MAX_MA +
              GLOW_STRIP_PIXELS * (GLOW_RED_MAX / 255.0f) * MA_PER_CHANNEL_FULL
              <= NEOPIXEL_BUDGET_MA - NEOPIXEL_MARGIN_MA,
              "neopixel worst case exceeds the power budget");

static void neopixel_task(void *arg) {
  log_i("neopixel task on core %d: glow red max %u/255, worst case ~%d mA of %d mA budget",
        xPortGetCoreID(), GLOW_RED_MAX,
        (int)(NEOPIXEL_IDLE_MA + CYLON_MAX_MA +
              GLOW_STRIP_PIXELS * (GLOW_RED_MAX / 255.0f) * MA_PER_CHANNEL_FULL),
        (int)NEOPIXEL_BUDGET_MA);

  glow_strip.begin();
  glow_strip.show();  // all off
  cylon_strip.begin();
  cylon_strip.show();

  const uint32_t PULSE_PERIOD_MS = 4000;
  const uint32_t CYLON_SWEEP_MS = 1200;    // one end to the other
  const uint32_t UPDATE_INTERVAL_MS = 20;  // ~50 Hz, smooth without flooding the bus

  // Per-pixel brightness of the Cylon eye and its trail, 0..1.
  float cylon_level[CYLON_STRIP_PIXELS] = {0};

  for (;;) {
    uint32_t now = millis();

    // Red glow.
    uint32_t phase_ms = now % PULSE_PERIOD_MS;
    float phase = (2.0f * PI * phase_ms) / PULSE_PERIOD_MS;
    float brightness = (sinf(phase - PI / 2.0f) + 1.0f) / 2.0f;  // 0..1, starts at 0

    uint8_t red = (uint8_t)(brightness * GLOW_RED_MAX);
    uint32_t color = glow_strip.Color(red, 0, 0);
    for (int i = 0; i < GLOW_STRIP_PIXELS; i++) {
      glow_strip.setPixelColor(i, color);
    }

    // Cylon: the eye bounces end to end (triangle wave), leaving a trail
    // that fades by CYLON_DECAY each frame. Fading the existing trail rather
    // than drawing it relative to the head means it follows the eye
    // naturally through the turnaround at each end.
    uint32_t t = now % (2 * CYLON_SWEEP_MS);
    float sweep = (t < CYLON_SWEEP_MS) ? (float)t / CYLON_SWEEP_MS
                                       : 2.0f - (float)t / CYLON_SWEEP_MS;  // 0..1..0
    float head = sweep * (CYLON_STRIP_PIXELS - 1);

    for (int i = 0; i < CYLON_STRIP_PIXELS; i++) {
      cylon_level[i] *= CYLON_DECAY;
    }
    // Split the head across the two pixels it sits between, so it glides
    // instead of stepping. The two weights sum to 1, which is what the
    // CYLON_MAX_MA bound relies on.
    int head_i = (int)head;
    float frac = head - head_i;
    cylon_level[head_i] = max(cylon_level[head_i], 1.0f - frac);
    if (head_i + 1 < CYLON_STRIP_PIXELS) {
      cylon_level[head_i + 1] = max(cylon_level[head_i + 1], frac);
    }

    for (int i = 0; i < CYLON_STRIP_PIXELS; i++) {
      float l = cylon_level[i];
      cylon_strip.setPixelColor(i, cylon_strip.Color((uint8_t)(l * CYLON_R),
                                                     (uint8_t)(l * CYLON_G),
                                                     (uint8_t)(l * CYLON_B)));
    }

    glow_strip.show();
    cylon_strip.show();

    vTaskDelay(pdMS_TO_TICKS(UPDATE_INTERVAL_MS));
  }
}
// ---------------------------------------------------------------------------


void setup() {
  Serial.begin(115200);

  // Native USB CDC only exists once the host has enumerated it, which takes a
  // second or two after boot. Without this wait, everything printed here is
  // written into the void. Bounded so the sketch still runs untethered.
  while (!Serial && millis() < 3000) {
    delay(10);
  }

  log_i("BigDripper valve test, %d coils", NUM_COILS);

  log_i("GPIO outputs:");
  for (int i = 0; i < NUM_COILS; i++) {
      pinMode(coils[i], OUTPUT);
      digitalWrite(coils[i], LOW);
      log_i("COIL%d -> GPIO%u", i + 1, coils[i]);
  }
  coils_begin();

  log_i("GPIO inputs:");
  for (int i = 0; i < NUM_ENCODER_CHANNELS; i++) {
      pinMode(encoder[i], INPUT_PULLUP);
      log_i("ENCODER %s -> GPIO%u", i == 0 ? "A": "B", encoder[i]);
  }

  log_i("setup() on core %d", xPortGetCoreID());

  // params_begin() must complete before the tasks below start, since
  // valve_task's print engine reads params from the moment it runs, and
  // valve_task's priority is high enough to preempt setup() (still running
  // as loopTask) as soon as it's created.
  params_begin();

  // Before valve_task starts, since the print engine pushes to the preview
  // queue. No-op in normal builds.
  console_preview_begin();

  // 4096-byte stacks: both tasks call log_i, and the vsnprintf underneath it is
  // the stack-hungry part. Priorities are above loopTask's 1 so neither is
  // starved by it; being on separate cores makes that mostly academic.
  xTaskCreatePinnedToCore(encoder_task,   "encoder",   4096, NULL, 3, NULL, ENCODER_CORE);
  xTaskCreatePinnedToCore(valve_task,     "valve",     4096, NULL, 2, NULL, VALVE_CORE);
  xTaskCreatePinnedToCore(neopixel_task,  "neopixel",  4096, NULL, 1, NULL, ENCODER_CORE);

  wifi_text_input_begin();
}

void set_coil_state(uint16_t bitVector) {
  uint16_t bit = 0x8000;  // bit 15 -> coils[0] (COIL1)
  uint32_t bank0_set = 0, bank0_clear = 0;
  uint32_t bank1_set = 0, bank1_clear = 0;

  for (int i = 0; i < NUM_COILS; i++) {
    bool on = (bitVector & bit) != 0;
    if (coil_is_bank1[i]) {
      if (on) bank1_set |= coil_mask[i]; else bank1_clear |= coil_mask[i];
    } else {
      if (on) bank0_set |= coil_mask[i]; else bank0_clear |= coil_mask[i];
    }
    bit >>= 1;
  }

#ifdef CONSOLE_PREVIEW_DRY_RUN
  // Dry run (Ticket 7.2): masks computed as usual so the timing is the same,
  // but no valve ever opens, in any mode.
  (void)bank0_set; (void)bank0_clear; (void)bank1_set; (void)bank1_clear;
#else
  // One write per bank per direction, instead of one digitalWrite() per
  // coil, so every coil switches within the same register access rather
  // than one at a time.
  GPIO.out_w1ts = bank0_set;
  GPIO.out_w1tc = bank0_clear;
  GPIO.out1_w1ts.val = bank1_set;
  GPIO.out1_w1tc.val = bank1_clear;
#endif
}

// --- Coil close timer -------------------------------------------------------
//
// A column's burst is ended by a one-shot esp_timer instead of the valve
// task polling millis(), so the close happens when the timer fires rather
// than up to 5 ms later on the next scan tick.
//
// The timer callback runs in the dedicated esp_timer task, a different
// thread from valve_task, so its close and the task's next open can race.
// coil_mux serializes the two set_coil_state() calls that can actually
// collide, and coil_generation guards against a stale timer: every open (or
// forced state change that must not be undone by an old timer) bumps the
// generation, and coil_armed_generation records which generation the
// currently-armed timer is allowed to close. If a new open/force happens
// before a late callback acquires the lock, the generation it captured no
// longer matches and it skips the close instead of stomping the newer state.
static esp_timer_handle_t coil_off_timer = NULL;
static portMUX_TYPE coil_mux = portMUX_INITIALIZER_UNLOCKED;
static volatile uint32_t coil_generation = 0;
static volatile uint32_t coil_armed_generation = 0;

static void coil_off_timer_cb(void *arg) {
  portENTER_CRITICAL(&coil_mux);
  if (coil_armed_generation == coil_generation) {
    set_coil_state(0x0000);
  }
  portEXIT_CRITICAL(&coil_mux);
}

void coil_timer_begin() {
  esp_timer_create_args_t args = {};
  args.callback = coil_off_timer_cb;
  args.name = "coil_off";
  esp_timer_create(&args, &coil_off_timer);
}

// Invalidates any in-flight close timer without changing the coils, so a
// stale close can't land after whatever is about to force the coils to a
// new state (priming/trace taking over mid-burst). Does not touch the
// coils itself — the caller is expected to set them right after.
static void coil_timer_invalidate() {
  esp_timer_stop(coil_off_timer);  // ESP_ERR_INVALID_STATE if already idle; fine to ignore
  portENTER_CRITICAL(&coil_mux);
  coil_generation++;
  portEXIT_CRITICAL(&coil_mux);
}

// True if the previous column's close hasn't fired yet, i.e. the column
// about to open would be an overrun. Call before coil_timer_open(), which
// closes-then-reopens regardless -- this is purely for counting/logging.
static bool coil_timer_is_pending() {
  return esp_timer_is_active(coil_off_timer);
}

// Opens a column's valves and arms the close timer for burst_us. No
// logging between the coil write and the timer start, per the "no log_*
// calls between opening and arming" rule -- a UART write here would add
// jitter to exactly the latency this exists to kill.
static void coil_timer_open(uint16_t bits, uint32_t burst_us) {
  esp_timer_stop(coil_off_timer);
  uint32_t my_gen;
  portENTER_CRITICAL(&coil_mux);
  coil_generation++;
  my_gen = coil_generation;
  set_coil_state(bits);
  portEXIT_CRITICAL(&coil_mux);
  coil_armed_generation = my_gen;
  esp_timer_start_once(coil_off_timer, burst_us);
}
// ---------------------------------------------------------------------------

// Naive test function for flipping all coils on / off
void test_GPIO_outputs() {
  while (true) {
    static unsigned tick = 0;

    // Serial.printf: always compiled in, plain text, you control the format.
    set_coil_state(0xFFFF);
    log_d("[%u] coils ON  (%lu ms)", tick, millis());
    delay(1000);

    // log_*: adds level, timestamp, file:line and function; compiled out entirely
    // when CORE_DEBUG_LEVEL is below the macro's level.
    set_coil_state(0x0000);
    log_d("[%u] coils OFF", tick++);
    delay(1000);
  }
}

// naive test function for reading encoder output
void test_encoder() {
  int a = digitalRead(encoder[0]);
  int b = digitalRead(encoder[1]);
  log_i("A:%d - B:%d", a, b);

}
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
void loop() {

  // demoLEDs();

  
  // Both jobs now live in their own pinned tasks, so loopTask has nothing to do.
  // It still has to yield: returning immediately would spin core 1 at full tilt
  // and starve the idle task. Deleting loopTask outright is the alternative, but
  // keeping it costs nothing and leaves somewhere to put ad-hoc test code.
  vTaskDelay(pdMS_TO_TICKS(1000));
}

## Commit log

2026-07-25 Initial hardware revision
    * Added KiCad files
    * Added picture of assembled board
    * Added PDF version of schematic
    [BigDripperController.kicad_pcb, BigDripperController.kicad_sch]
2026-07-25 Added valve control example code
2026-08-13 Quadrature decoder ok
    * pinned decoder and valve control to separate cores
2026-09-15 Added Spleen 8x16 font
    * Because of a known issue in the ESP ecosystem (USB port not
    re-enumerating after a reset, we now use the UART port for
    flashing and monitoring
    * Hardware fixes. Cut the traces for pulldowns on strapping
    pins and also D+/D- (yeah, yeah...)
    [example_valve_control.cpp]
2026-09-17 Updated params with burst mode solenoid activation
2026-09-28 Added support for priming and printehead testing
2026-10-07 Precise valve burst timing + speed-adaptive burst length
    Ticket 1: register-write set_coil_state(), event-driven valve loop
    (encoder ISR wakes the print engine directly), and a hardware esp_timer
    close with a generation-counter race guard, replacing the 5ms-polling
    coil_on/coil_off_at_ms logic.
    Ticket 2: burst duration now scales with riding speed instead of a
    fixed column_burst_ms, so dots stay short and separate at bike speed.
    Adds burst_duty_pct/min_burst_ms params (with /params UI + validation),
    an EMA of the measured column period, the clamped burst computation,
    and overrun counting/logging.
    Code-complete and builds clean (pio run); not yet bench/ride-verified
    on real hardware.
    Co-Au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
    [example_valve_control.cpp]
2026-10-07 Release build: compile out serial logging (CORE_DEBUG_LEVEL=0)
    All log_* calls compile to nothing at level 0, so the firmware writes
    nothing to the UART beyond the ROM/bootloader banner. A log write blocks
    the calling task once the UART FIFO fills, which can stall the print
    engine between columns. Raise the level to 3 on the bench to get the
    print engine's period_us/burst_us/overruns line back.
2026-10-09 Add encoder-driven vertical-line test pattern
    "Lines on" on the web page replaces the text with a full vertical line
    (all coils) every N columns, N set on the page and stored in NVS
    (test_line_spacing, default 10). Unlike trace mode it runs through the
    normal per-column path, so it exercises the speed-adaptive burst and
    overrun handling at real riding speed and the spacing is a fixed
    distance on the ground.
    Starting or stopping the pattern restarts the scan from column 0 without
    firing it, so pressing the button while standing still doesn't spray a
    line.
    [example_valve_control.cpp]
2026-10-09 New 16-row fonts with bold, ÆØÅ and emoji; fix mirrored print
    Text came out mirrored on the ground: COIL1 printed the top row of each
    glyph. The top row now goes to COIL16 (TOP_ROW_ON_COIL16 in font.cpp).
    The Spleen 8x16 font only used 10 of the 16 nozzles and had A-Z, 0-9 and
    space. It is replaced by fonts generated from font_design/gen_font.py,
    which builds every glyph from strokes so both weights stay consistent:
    - regular: 1-column verticals, 2-row horizontals, 9 columns wide
    - bold: 2-column verticals, 3-row horizontals, 10 columns wide
    - A-Z, ÆØÅ, 0-9, . , ! ? - : ' and space, all 16 rows tall
    - 16x16 emoji, one style for both weights: :-) :-( :-D :-| :-/ ;-) :-O
    :-P (nose op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
    [example_valve_control.cpp]
2026-10-09 Mobile UI: exclusive modes, emoji shortcodes, font selector
    - One print mode at a time (Off/Prime/Trace/Lines/Text) in mode.{h,cpp},
    replacing priming/trace/test-pattern flags. Boots in Text, never Prime.
    - POST /mode, GET /status (JSON), POST /lines/spacing; no-store caching.
    - Mobile page: sticky green/red mode toolbar, live /status polling,
    "not connected" note, Lines spacing only while Lines is on.
    - Emoji are Slack-style shortcodes only (:smile: etc.); ASCII faces print
    as text. Buttons under the text box draw each glyph from /emoji.json.
    - Length limit counts printed glyphs (font_glyph_count), with a live
    "N left" counter on the page.
    - Font per queued message: Spleen (original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
    [example_valve_control.cpp]
2026-10-09 Inverted text: per-message Invert toggle
    font_render() can bit-invert every column (spacing included) and frames
    the text with FONT_INVERT_EDGE (2) all-on columns on each side, so the
    start and end of an inverted message stay visible on the ground.
    The flag is stored with each queued message like the font: /set takes
    invert=1, /status reports it, and the print engine re-renders when it
    changes. The page's Invert placeholder is now a working toggle,
    remembered per phone, and the queue shows "inverted" messages.
    [example_valve_control.cpp]
2026-10-09 Console preview and dry-run build options
    Two new PlatformIO envs for checking what the head prints at the bench:
    - preview: every column that fires is drawn on the CP2102 port (Serial0)
    as 16 chars, COIL1 on the left, '#' open / '.' closed. Rotated 90
    degrees anticlockwise it reads like the ground print. Context lines for
    new messages, mode changes, skipped columns and dropped lines.
    - preview-dry: same, with CONSOLE_PREVIEW_DRY_RUN so set_coil_state()
    never writes the GPIOs. Boot banner, "dry_run":true in /status and a
    DRY RUN line on the page.
    The print engine only does zero-timeout pushes onto a FreeRTOS queue,
    after the close timer is armed; a low-priority task on core 0 dra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
    [console_preview.cpp, example_valve_control.cpp]
2026-10-11 Print engine core: host-testable engine with position/time wakes
    Adds lib/drip_core, the print engine as plain C++ with no Arduino,
    FreeRTOS or hardware: modes, text queue, speed estimation and the
    column firing strategy (ColumnScanner). The shell passes in encoder
    samples and the time; step() returns a coil command and a Wake
    (position window + deadline), so standstill costs no wake-ups and
    scanning needs one step per column rather than per encoder edge.
    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
2026-10-11 PCNT bench test on Arduino 3 / IDF 5.5
    Standalone sketch (env pcnt-test, pioarduino 55.03.312-1) that runs the
    hardware pulse counter on the encoder next to the old software decoder,
    with engine-style moving windows on PCNT watch points.
    Findings on the board: moved watch points never fire unless the counter
    is cleared afterwards; with a clear on every move (count folded into a
    64-bit offset) every crossing fired, ISR on core 1, 5-19 us ISR-to-task,
    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
2026-10-11 Firmware on the print engine core: PCNT encoder, GPTimer bursts, print task
    Replaces the old print loop with lib/drip_core running in a print task on
    core 1, which is also where the encoder (PCNT, clear-on-move watch point
    windows) and burst close timer (GPTimer) interrupts live. WiFi, web and
    neopixels stay on core 0. The print task wakes only when the encoder
    leaves the engine's window, at a deadline, or for a request.
    printer.h is the one way in: enqueue, set mode, set params and status
    are requests the print task answers between steps, so the engine needs
    no locks. Settings are read, checked and saved as a whole, so a rejected
    /params form no longer saves half of itself. HTTP endpoints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
2026-10-11 Web UI as files, JSON API, event stream, live coil view, letter spacing
    - web/: the main page, settings page and a live view, as plain files gzipped
    into the firmware at build time by scripts/embed_web.py.
    - src/web.cpp: ESPAsyncWebServer (async_tcp task on core 0) with a JSON
    API built on ArduinoJson (documented in web/API.md), replacing the old
    form posts and inline HTML. Errors are JSON with real status codes, and
    settings are checked and saved as a whole.
    - Event stream (/api/events): status when it changes, the print task's
    history, and a clock. The page fills gaps from /api/history and only
    marks what the board itself lost.
    - drip::Ring: a lock-free ring the print task reco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
2026-10-11 Stretch text at speed; print forward only
    ColumnScanner now lays columns out one at a time as they're entered,
    instead of from a fixed origin. Each column's width is counts_per_column,
    widened at speed so it takes at least min_column_us to cross (up to
    max_stretch_pct), so text gets wider on the ground rather than its
    columns getting too short for the valves. Burst length follows the
    stretched column, so dots scale with it. Off by default (min_column_ms 0).
    Printing is forward only: rolling back fires nothing (and doesn't wake
    the print task), and printing resumes once the wheel is back past the
    furthest point reached. A column width change applies from the next
    column.
    Settings min_column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
2026-10-11 Bluetooth: the API over BLE for the page served elsewhere
    src/api.cpp holds the operations, shared by HTTP (web.cpp) and a NimBLE
    GATT service (ble.cpp): framed requests/replies plus status, packed history
    and clock notifications. web/transport.js picks HTTP or Web Bluetooth.
    Settings move onto the main page, password sent by the page.
2026-10-11 Clearer settings, and a simulator built from the engine
    Settings are grouped, named for what they do, with a help line and notes
    worked out from the form (sizes on the ground, speeds where things change).
    Stretching is set as a speed (stretch_above_kmh) instead of a column time.
    The pure settings code moves to src/settings.cpp.
    The simulator runs lib/drip_core, the fonts and settings.cpp compiled to
    WebAssembly (sim/, web/sim.wasm) over a simulated ride, with a water model
    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
2026-10-11 Host the web UI on Cloudflare; API version check; offline page
    scripts/deploy_pages.sh publishes web/ as a Cloudflare Worker serving static
    files. The board reports its API version in the status and the page warns
    when it differs from its own. On the hosted page a service worker (sw.js)
    keeps it working offline once opened.
2026-10-18 Added updated schematic and layout.
    * Added production files for 1.1
2026-10-23 Added STL files
